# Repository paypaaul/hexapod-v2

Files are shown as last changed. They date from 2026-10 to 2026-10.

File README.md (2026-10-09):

# Hexapod v2

Robot esapode a 18 gradi di libertà (6 zampe × 3 servo MG996R), stampato in 3D e comandato da un ESP32-S3 con camera e una SSC-32. Progetto personale, in fase di progettazione CAD.

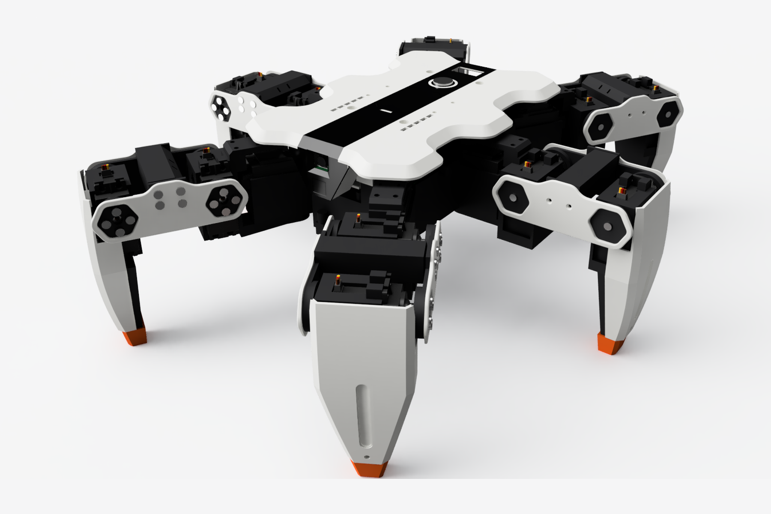
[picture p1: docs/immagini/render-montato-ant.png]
Render del robot (Fusion, colori per materiale)


Altri render: [da dietro](docs/immagini/render-montato-post.png), [di fianco](docs/immagini/render-montato-fianco.png), [esploso della zampa](docs/immagini/render-esploso-zampa.png), [esploso del corpo](docs/immagini/render-esploso-corpo.png).

## Dove guardare

| Documento | Contenuto |
|---|---|
| [Progetto meccanico](docs/progetto-meccanico.md) | zampa, corpo, assieme, verifiche di movimento, cavi, massa |
| [Decisioni](docs/decisioni.md) | registro delle scelte con il perché |
| [BOM](docs/BOM.md) | distinta base, schema di alimentazione, viteria, domande aperte |
| [Studio dei componenti](docs/studio-componenti.md) | servo, alimentazione, batteria, giunti, stampa |
| [Dimensionamento](docs/dimensionamento.md) | massa, geometria, coppie e assetti |
| [Dimensioni dei componenti](docs/dimensioni-componenti.md) | quote dei componenti con la fonte |
| [Ricerca](docs/ricerca/) | proposte e revisioni indipendenti di zampa e corpo |

## Cartelle

- `cad/script/`: script Python che costruiscono il modello in Fusion (`corpo.py`, `zampa.py`, `assieme.py`).
- `cad/stl/`: STL delle parti già pronte per i provini.
- `cad/modelli/`: fonti dei modelli STEP di terzi.
- `cad/render/`: render schematici del modello.
- `calc/`: calcoli di statica, andature, escursioni e cavi.

Lo stato del lavoro e i prossimi passi sono in [CLAUDE.md](CLAUDE.md).

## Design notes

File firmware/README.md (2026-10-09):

# Firmware dell'esapode

Firmware per l'ESP32-S3 (scheda UICPAL ESP32-S3-CAM N16R8) in **C++17 su ESP-IDF, senza Arduino**. Architettura in `docs/software.md` (capitoli 2 e 4); qui c'è la prima parte della fase S0: il nucleo provato sul PC e lo scheletro del firmware che compila.

## Struttura

```
firmware/
  CMakeLists.txt            progetto ESP-IDF (build minima: solo main e i componenti che richiede)
  sdkconfig.defaults        16 MB di flash, PSRAM octal, partizioni, OTA con ritorno, watchdog a 1 s
  partitions.csv            tabella di software.md 2.8, con due slot OTA da 4 MB
  main/                     app_main e compiti FreeRTOS (scheletri, vedi sotto)
  components/nucleo/        C++17 puro, senza dipendenze da ESP-IDF: si compila sul chip e sul PC
    include/nucleo/
      robot_generato.hpp    GENERATO da tools/genera_header.py (non si modifica a mano)
      tipi.hpp              vettori, angoli di una zampa, posa, maschera d'appoggio
      cinematica.hpp        diretta e inversa di zampa e corpo
      statica.hpp           carichi sui piedi, coppie stimate, margine di stabilità
      guardia.hpp           guardia del fotogramma intero (software.md 2.5)
      andatura.hpp          tripode a fase continua, identico a cad/script/assieme.py -> pose_tripode
      servo.hpp             angolo -> impulso, taratura, modello del servo per la posa prevista
  test_host/                test del nucleo sul PC: CMake, ctest, Unity, sanitizer
    vettori_generati.hpp    GENERATO da tools/genera_vettori.py
```

Fuori da `firmware/`: `tools/genera_header.py`, `tools/genera_vettori.py`, `tools/riferimento.py` (andatura di riferimento in Python), `tests/` (pytest), `ruff.toml`, `.github/workflows/ci.yml`.

## Versione di ESP-IDF

**ESP-IDF v6.1** (pubblicata il 27 agosto 2026): l'ultima versione stabile pubblicata da almeno due settimane al 9 ottobre 2026, ed è quella scelta in `docs/software.md` (tabella del capitolo 1). La stessa versione è fissata nel CI (`ESP_IDF_VERSIONE` in `.github/workflows/ci.yml`, immagine Docker `espressif/idf:v6.1`): si cambiano insieme.

Installazione sul Mac (fatta il 9 ottobre 2026, solo per l'esp32s3):

```sh
git clone -b v6.1 --depth 1 --recursive --shallow-submodules https://github.com/espressif/esp-idf.git ~/esp/esp-idf
~/esp/esp-idf/install.sh esp32s3
```

Gli strumenti stanno in `~/.espressif` (compilatore `xtensa-esp-elf` 15.2.0, ambiente Python `idf6.1_py3.12_env`). In `~/esp-idf` resta un'installazione precedente della v6.0: questo progetto usa `~/esp/esp-idf`.

## Compilare il firmware

```sh
. ~/esp/esp-idf/export.sh
cd firmware
idf.py build          # la prima volta crea sdkconfig da sdkconfig.defaults (sdkconfig non va in git)
idf.py size           # occupazione di flash e RAM
```

Risultato al 9 ottobre 2026: compila senza avvisi; `hexapod.bin` 174 KB, il 4 % dello slot OTA da 4 MB.

Non provato sul chip: la scheda non c'è ancora. Quando ci sarà: `idf.py -p <porta> flash monitor` (console sulla CH340).

## Provare il nucleo sul PC

```sh
cmake -S firmware/test_host -B firmware/test_host/build -G Ninja   # sanitizer attivi: -DNUCLEO_SANITIZER=OFF per toglierli
cmake --build firmware/test_host/build
ctest --test-dir firmware/test_host/build --output-on-failure -V    # -V stampa gli scarti misurati
```

Unity si scarica alla prima configurazione (FetchContent), alla stessa revisione che ESP-IDF v6.1 porta in `components/unity` (v2.6.0_RC1), con l'hash dell'archivio controllato. Nucleo e test si compilano con `-Wall -Wextra -Wpedantic -Wshadow -Wdouble-promotion -Werror` e, di default, con AddressSanitizer e UndefinedBehaviorSanitizer.

Cosa controllano (criteri di `docs/software.md` 6.3) e cosa si è misurato il 9 ottobre 2026 con Apple clang 21 (uguale in Debug con i sanitizer e in Release):

| Prova | Criterio | Misurato |
|---|---|---|
| Diretta contro il CAD (`robot/pose_cad.json`, 75 pose) | ≤ 0,05 mm | 0,00009 mm |
| Diretta contro `tools/descrizione.py` (810 punti) | ≤ 0,001 mm | 0,00005 mm |
| Inversa contro il Python, andata e ritorno | ≤ 0,01° | 0,0004° (punta ritrovata a 0,0004 mm) |
| Inversa delle punte lette dal CAD (66 pose) | ≤ 0,01° | 0,002° |
| Andatura contro i cicli del CAD (arrotondati a 0,01°) | ≤ 0,006° | 0,005° |
| Andatura contro `tools/riferimento.py` (240 pose a fasi diverse) | ≤ 0,01° | 0,00003° |
| Pose dei 6 cicli verificati nel CAD | nessun limite geometrico violato | nessuno; a 70/70 rifiuto per la coppia (sotto) |
| Casi d'urto: femore a −60°, vicine a 40° una verso l'altra, ginocchio sotto la tabella | rifiutati | rifiutati con il motivo giusto |
| Statica contro `calc/statica_tripode.py`, riga per riga | carichi ≤ 1e-4 kgf, coppie ≤ 1e-3 kgf·cm | 5e-7 kgf, 5e-6 kgf·cm |
| Regressione a 100/45 | femore al 51 % ± 1, margine 59 mm | 51,38 % (5,651 kgf·cm), 59,21 mm |
| Andatura a 50 Hz, ciclo da 1,2 s, tre cicli per assetto | nessun salto oltre 250°/s; piedi in appoggio fermi ≤ 0,5 mm | salto massimo 4,06° a fotogramma (203°/s); piedi fermi entro 0,0002 mm |
| Partenza, rotazione e arresto con la rampa dei parametri | ogni fotogramma accettato dalla guardia | 360 fotogrammi accettati, salto massimo 3,8° |

**Coppia a 70/70.** Le pose del ciclo a tripode a 70/70 (e della rotazione sul posto a 70/70) passano tutti i limiti geometrici, ma la coppia stimata arriva al 75 % (74 % nella rotazione) dello stallo, oltre il rifiuto al 70 % di `robot.yaml`; la tabella del 4.2 di `software.md` dà lo stesso 75 %. Nel CAD si è verificata l'assenza di urti, non la coppia. La guardia li rifiuta: a 70/70 il firmware dovrà usare un'andatura con più piedi a terra. Il test lo controlla esplicitamente.

## Test Python e file generati

```sh
python3 -m venv .venv && .venv/bin/pip install -r tests/requirements.txt
.venv/bin/python -m pytest tests            # descrizione contro il CAD, statica, file generati aggiornati
.venv/bin/ruff check .
```

`robot_generato.hpp` e `vettori_generati.hpp` si rigenerano dopo ogni modifica di `robot/robot.yaml` o una nuova esportazione dal CAD (prima `python3 tools/descrizione.py --aggiorna-hash`):

```sh
python3 tools/genera_header.py
python3 tools/genera_vettori.py
```

L'uscita è deterministica; il CI la rigenera e fallisce se differisce da quella nel commit, o se `cad_sha256` di `robot.yaml` non è quello di `cad.json`.

## La guardia

Un fotogramma (posa delle 18 articolazioni più i piedi a terra) è accettato solo se rispetta tutti i limiti di `robot.yaml -> guardia`: imbardata ±30°, somma tra vicine entro 56° con i segni di `robot.yaml` (a sinistra imb_A − imb_M e imb_M − imb_P, a destra il contrario), femore da −45° a +82°, ginocchio da γmin(α) + 3° (fra due righe della tabella vale il massimo) a 177°, corsa ±80° attorno al calettamento, 250°/s per giunto rispetto al fotogramma precedente, baricentro ad almeno 20 mm dai lati del poligono d'appoggio, coppia stimata sotto il 70 % dello stallo (oltre il 55 % e il 60 % dà il livello di avviso e di tempo limitato, che userà la macchina a stati). Il singolo giunto non si tronca mai: l'esito dice il primo motivo del rifiuto (zampa, giunto, valore, limite) e tutti i limiti violati; chi comanda tiene il fotogramma precedente o riduce il comando. I limiti morbidi possono solo stringere quelli rigidi (`LimitiGuardia::stringi`).

Ipotesi della statica, le stesse di `calc/`: corpo orizzontale, baricentro al centro del corpo, forze ai piedi verticali. Con più di tre piedi a terra il problema è iperstatico e il nucleo prende la ripartizione a norma minima (S): la ripartizione vera dipende dalle cedevolezze.

## Cosa è uno scheletro

I compiti di `docs/software.md` 2.2 esistono tutti, con il loro core, la priorità e il ritmo; nel codice sono marcati `SCHELETRO`.

| Compito | Core | Priorità | Ritmo | Oggi |
|---|---|---|---|---|
| `ctrl` | 1 | 22 | 50 Hz da un timer hardware, interruzione sul core 1 | **fa il ciclo del nucleo in modo OMBRA**: andatura a tripode a 100/45, IK del corpo, guardia, impulsi, posa prevista; niente alla SSC-32, rail spento. Si iscrive al watchdog. Ogni secondo scrive nel log cicli, rifiutati e durata massima del ciclo |
| `sens` | 1 | 20 | 100 Hz | gira a vuoto |
| `infer` | 1 | 3 | 5 Hz | gira a vuoto |
| `comm` | 0 | 15 | a evento | gira a vuoto |
| `cam` | 0 | 10 | 15 Hz | gira a vuoto |
| `telem` | 0 | 8 | 50 Hz | gira a vuoto |
| `servizio` | 0 | 3 | a evento | gira a vuoto |

All'avvio `app_main` porta GPIO42 (rail dei servo) basso, scrive versione e impronta di `cad.json`, fa un autotest del nucleo (la posa iniziale dell'andatura deve passare la guardia) e solo allora avvia i compiti.

Mancano: macchina a stati e sequenza d'accensione (2.6), driver della SSC-32 (2.4), comandi e rete, sensori, telemetria, taratura in NVS (2.7), OTA con autotest (2.8), andature a coppie e a onda, politica.

## Partizioni

| Partizione | Indirizzo | Dimensione |
|---|---|---|
| `nvs` | 0x9000 | 24 KB |
| `nvs_cal` (taratura) | 0xF000 | 16 KB |
| `otadata` | 0x13000 | 8 KB |
| `phy_init` | 0x15000 | 4 KB |
| `ota_0` | 0x20000 | 4 MB |
| `ota_1` | 0x420000 | 4 MB |
| `coredump` | 0x820000 | 64 KB |
| `storage` (LittleFS) | 0x830000 | 7,8 MB, fino a 16 MB |

Gli indirizzi non vanno cambiati dopo la prima installazione: l'OTA non riscrive la tabella.

## Integrazione continua

`.github/workflows/ci.yml`, quattro job: `python` (ruff e pytest), `nucleo` (CMake e ctest con i sanitizer, con gcc e con clang), `firmware` (ESP-IDF v6.1 installato dal repository di Espressif come sul Mac, con la cache: senza Docker, perché il 9 ottobre Docker Hub non rispondeva ai runner; dimensione dell'immagine contro lo slot OTA, binari allegati), `generati` (impronta di `cad.json`, header e vettori rigenerati, `git diff --exit-code`).

**Passo successivo: il job `qemu`** (`software.md` 6.4). Una configurazione dedicata del firmware (per esempio `sdkconfig.qemu` con la console sulla UART0 e senza camera, Wi-Fi e sensori) si avvia nel QEMU di Espressif per l'esp32s3 (`idf.py qemu`, nell'immagine Docker dell'IDF), stampa versione e autotest e, in uno scenario scritto, emette i comandi attesi per la SSC-32; il job confronta l'uscita. Prova la macchina a stati e il nucleo, non lo stack completo: il QEMU dell'S3 non emula Wi-Fi, Bluetooth, USB, I2C, RMT né la matrice dei GPIO. Serve prima il driver della SSC-32 con il backend simulato, e va verificato se la UART1 è emulata; se non lo è, lo scenario usa la console.

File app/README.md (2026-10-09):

# Gemello digitale nel browser (app/)

Il robot in 3D, dall'URDF generato (`robot/generati/esapode.urdf`) con le mesh dei segmenti esportate dal CAD, che
riproduce il **tripode** e la **rotazione sul posto**. Cursori per h (altezza dell'asse dei femori), xf0 (distanza del
piede dall'asse del femore), giro (gradi di rotazione del corpo a ogni passo) e periodo del ciclo. È la prima forma del
gemello di `docs/software.md` 6.6; poi l'app servita dal robot mostrerà le pose comandate e previste che arrivano dalla
telemetria.

**Le pose sono comandate, non misurate**: le calcola il generatore d'andatura e l'app lo scrive in cima al pannello. Il
corpo si sposta come farebbe se i piedi in appoggio non scivolassero. La guardia (ginocchio minimo, somma tra vicine,
velocità) qui non c'è: l'app segnala in rosso solo gli angoli oltre i fine corsa meccanici dell'URDF.

## Come si usa

Serve Node.js 22.18 o più recente (`brew install node`). Nessun servizio esterno: tutto è nella build.

```
cd app
npm ci
npm run dev          # http://localhost:5173, ricarica a ogni modifica
npm test             # formule contro il CAD (node:test, senza compilazione)
npm run build        # dist/, da servire come file statici (anche dal robot)
npm run dimensione   # controlla la dimensione di dist/
```

Una vista si può condividere con l'indirizzo: `?andatura=rotazione&h=70&xf0=70&giro=20&periodo=1.5&fase=0.3`.

## Cosa c'è

| Percorso | Contenuto |
|---|---|
| `src/andatura.ts` | tripode e rotazione sul posto, con la cinematica inversa: stesse formule di `cad/script/assieme.py` → `pose_tripode` e di `sim/andatura.py` |
| `src/geometria.ts` | coxe, Lc, Lf, Lt e limiti letti dall'URDF |
| `src/main.ts` | scena three.js, caricamento con urdf-loader, comandi, animazione |
| `scripts/modelli.mjs` | prepara `public/modelli/` (generata, ignorata da git): copia l'URDF e converte gli STL in GLB compatti |
| `scripts/dimensione.mjs` | limiti della build: modelli sotto 1 MB, totale sotto 2 MB |
| `test/andatura.test.ts` | geometria uguale a `cad.json`, pose uguali a `cad.json` → `cicli_verificati` entro 0,01°, costanti uguali a `robot.yaml` |

### Perché le pose le calcola il TypeScript

I cursori sono continui: con le pose precalcolate in Python servirebbe una griglia di h × xf0 × giro × fasi, pesante
e comunque a scatti. Le formule sono poche righe e restano uguali alle altre grazie al test, che le confronta con le
stesse pose del CAD usate per il generatore Python e per il nucleo C++. Le costanti che l'URDF non contiene (tripodi,
assetto, passo, alzata) sono in `src/andatura.ts` e il test le confronta con `robot.yaml`.

### Mesh

Gli STL dei segmenti pesano 2,4 MB (il corpo 2 MB). `scripts/modelli.mjs` salda i vertici ripetuti, scrive le
posizioni come interi a 16 bit con passo di 0,01 mm (estensione glTF KHR_mesh_quantization) e lascia fuori le normali
(ombreggiatura piatta): 444 KB in tutto, senza decimare e senza dipendenze. Build intera: circa 1,2 MB (three.js è
quasi tutto il resto).

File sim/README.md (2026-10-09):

# Simulazione (sim/)

Gemello fisico del robot in MuJoCo, comandato come il robot vero: comandi ASCII della SSC-32, impulsi ogni 20 ms,
servo senza retroazione. È la parte "SIL" della fase S0 (`docs/software.md`, 6.5 e 7).

## Cosa c'è

| File | Contenuto |
|---|---|
| `modello/esapode.xml` | MJCF **generato** da `tools/genera_modelli.py`: non si modifica a mano |
| `ssc32_emu.py` | emulatore della SSC-32 (`SSC32`) e conversione impulsi ↔ angoli con `robot.yaml` (`Canali`) |
| `servo.py` | modello dei servo attorno agli attuatori dell'MJCF: banda morta, servo liberi, coppia all'uscita |
| `andatura.py` | tripode e rotazione sul posto in Python: porting di `cad/script/assieme.py` → `pose_tripode` |
| `simulazione.py` | catena completa: comandi → emulatore → servo → fisica a passi di 2 ms |
| `sil.py` | prova SIL del tripode a comandi aperti, con le misure; si lancia anche da riga di comando |
| `tests/` | test con pytest, senza schermo |
| `requirements.txt` | versioni fissate (MuJoCo 3.14.0) |

## Come si usa

Dalla radice della repo, con un ambiente virtuale (`.venv`, ignorato da git):

```
python3 -m venv .venv && printf '*\n' > .venv/.gitignore
.venv/bin/pip install -r sim/requirements.txt
.venv/bin/python tools/genera_modelli.py            # rigenera URDF e MJCF dopo un cambio di robot.yaml o cad.json
.venv/bin/python tools/genera_modelli.py --controlla
.venv/bin/python -m pytest sim/tests -q              # circa 3 s
.venv/bin/python sim/sil.py                          # 20 s di tripode a 100/45, stampa le misure
.venv/bin/python sim/sil.py --giro 30                # rotazione sul posto
.venv/bin/python sim/sil.py --h 70 --xf0 70          # altri assetti
.venv/bin/python -m mujoco.viewer --mjcf sim/modello/esapode.xml   # per guardarlo (con lo schermo)
```

Nel visualizzatore i gruppi 2 e 3 sono le mesh e le primitive di collisione; la posa "in_piedi" è fra i keyframe.

## Il modello

- Un corpo libero e tre segmenti per zampa, con lo zero dei giunti nella posa "come costruita" del CAD:
  `g_coxa_<z>` = imbardata, `g_femore_<z>` = alpha (asse −Y), `g_ginocchio_<z>` = gamma − 90 (asse −Y). Fine corsa
  meccanici da `cad.json`; la tabella del ginocchio minimo non c'è, la applica la guardia.
- Masse e inerzie: somma delle parti di `cad.json` per segmento, con il trasporto al baricentro; i 360 g non modellati
  sul corpo, distribuiti come il corpo. Massa totale 2943,2 g (`robot.yaml` dice 2945).
- Collisioni con primitive ricavate da `cad.json` e dalle mesh: chiglia, scafo, carapace e sei lobi per il corpo; la
  culla del servo del femore per la coxa; due capsule (una per fianco) per il femore; culla, stinco e sfera del piede
  (raggio 5,6 mm) per la tibia. Riproducono il CAD: due vicine si toccano fra 31 e 32 gradi ciascuna, il ginocchio
  minimo sta da 1 grado sotto a 4 sopra la tabella del CAD, nessun urto nelle 64 pose verificate.
- Sensori: contatto (`touch`) per ogni piede, IMU (accelerometro, giroscopio, assetto) al centro del vano sotto il
  vassoio (`predisposizioni.md`, X4; la x esatta è da fissare, C).
- Contatti: attrito 0,8 (centro della randomizzazione di `software.md` 4.4, S) e `solref` 0,005 s. Con il valore di
  MuJoCo (0,02 s) il contatto è cedevole e cambia i risultati: vedi sotto.

### Servo

| Grandezza | Valore | Da dove |
|---|---|---|
| Coppia massima (`forcerange`) | 1,079 N·m | stallo 11 kgf·cm a 6 V (V) |
| Smorzamento del giunto | 0,144 N·m·s/rad | stallo / velocità a vuoto (0,14 s/60° = 7,48 rad/s, V): la retta coppia-velocità del motore a piena tensione |
| `kp` | 12,4 N·m/rad | stallo raggiunto a 5° di errore (S, da identificare: `software.md` 4.6) |
| Banda morta | ±2,5 µs = ±0,225° | larga 5 µs (V), in gradi con 11,1 µs/° (S); applicata da `servo.py` |

Mancano ritardo proprio del servo, gioco, offset di taratura e variazione con la tensione: arrivano con
l'identificazione dei servo (S4). Il ritardo degli impulsi (un fotogramma da 20 ms) c'è già, dall'emulatore.

## Emulatore della SSC-32

Comandi ASCII: gruppi `#<ch>P<us>[S<us/s>]…[T<ms>]`, `#<ch>P0`, `STOP <ch>` e `#<ch>STOP`, `Q`, `QP <ch>`, `VER`;
`<esc>` annulla la riga. Interpolazione lineare dei gruppi, un fotogramma di impulsi ogni 20 ms, campo 500–2500 µs.
Uscita verso i servo con canali, versi, calettamento e µs per grado di `robot.yaml`.

Da confrontare con il clone al banco (S1, passo B1): comportamento dopo `P0`, troncamento di `QP`, stringa di `VER`,
tempi di risposta. Il modo binario e il tempo di trasmissione sulla seriale non ci sono ancora.

## Prova SIL (tests/test_sil.py)

Un "firmware" Python manda ogni 20 ms un gruppo con i 18 canali e `T20`; nessuna retroazione. Assetto 100/45, passo
60, alzata 30, periodo 1,0 s (120 mm/s; velocità comandate fino a 215°/s, sotto i 250 della guardia), rampa di passo
e giro sul primo ciclo, poi 20 s. Si prova il tripode dritto e la rotazione sul posto di 30° a passo.

| Verifica | Soglia e perché | Dritto | Giro 30 |
|---|---|---|---|
| Non cade | asse dei femori sopra h − alzata/2 = 85 mm; inclinazione sotto la posa sicura a 100/45 (25°, `software.md` 2.6); solo i piedi a terra | 97,8–99,2 mm; 0,20° | 97,7–99,2 mm; 0,14° |
| Urti fra parti | nessuno | nessuno | nessuno |
| Scivolamento dopo l'atterraggio | spostamento del piede lasciato libero dalla banda morta dei tre servo: 1,26 mm | 0,53 mm | 0,54 mm |
| Scivolamento per appoggio intero | 10 % del passo, 6 mm | 2,73 mm | 4,03 mm |
| Avanzamento o rotazione | entro il 10 % del comandato | 2305 mm su 2340 | 1143° su 1170 |
| Coppia | sotto il 60 % dello stallo (`robot.yaml` → guardia) | coxa 43 %, femore 51 %, ginocchio 49 % | 52 %, 52 %, 35 % |

Numeri del 9 ottobre 2026, macOS. Il femore al 51 % coincide con `calc/statica_tripode.py` (51,4 %).

Cose da sapere:

- **Atterraggio**: il volo di `pose_tripode` torna avanti a velocità costante e il piede arriva a terra ancora in moto
  (240 mm/s rispetto al pavimento): striscia 2–3 mm nei primi 50 ms dell'appoggio, poi resta fermo. Il generatore del
  firmware, con una Bézier che arriva a velocità zero (`software.md` 4.2), dovrebbe toglierlo.
- **Partenza**: senza la rampa (`sil.py --avvio 0`) il tripode d'appoggio passa da fermo a 120 mm/s in un fotogramma e
  il ginocchio posteriore tocca il 76 % dello stallo per qualche decina di millisecondi; a regime resta sotto il 50 %.
- **Rigidezza dei contatti**: con il `solref` di MuJoCo (0,02 s) il corpo cede di più, i piedi caricati strisciano fino
  a 3 mm e il femore tocca l'83 % agli atterraggi: la prova non passerebbe. Con 0,01 s: 1,5 mm e 58 %. Il valore
  scelto (0,005 s) è il più rigido stabile con il passo di 2 ms; va confermato confrontando simulazione e robot (S4).
- Altri assetti, senza asserzioni (stessa prova, `sil.py --h … --xf0 …`): nessuno cade né urta, ma negli assetti bassi
  la coppia sale e i piedi caricati strisciano oltre la soglia di 100/45 (in tutti la soglia vale 1,26 mm calcolata
  a 100/45):

  | Assetto | Coppia massima coxa / femore / ginocchio | Scivolamento dopo l'atterraggio, massimo |
  |---|---|---|
  | 130/25 | 41 / 51 / 50 % | 1,63 mm |
  | 80/60 | 41 / 59 / 56 % | 1,36 mm |
  | 70/70 | 35 / 81 / 66 % | 2,18 mm |

  A 70/70 il tripode supera il 60 % (in `docs/software.md` 4.2 il calcolo statico dà 75 %): conferma che negli assetti
  bassi serve l'andatura a coppie o a onda.

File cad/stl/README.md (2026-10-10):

# STL delle parti stampate

Esportati da Fusion il 10 ottobre 2026 (design "Hexapod v2.1.0", dopo D-066) con `cad/script/esporta_stl.py`. Ogni file è nella terna del suo componente: terna della zampa per le parti della zampa, terna del robot per quelle del corpo. Gli orientamenti qui sotto sono proposte: li confermi tu nello slicer. Sono file di prova: le quote marcate C (squadretta, giochi, forzamenti) si confermano con il provino.

Materiali (scelta dell'utente, D-065): **PETG-CF nero** per le parti funzionali, **PLA** per le placche (bianco per ora; fascia, visiera, gonne e sportellino in un secondo colore, nero), **TPU 95A arancio** per i piedini.

## Zampa (sei di ognuna)

| File | Materiale | Orientamento di stampa proposto | Note |
|---|---|---|---|
| `Tibia.stl` | PETG-CF | fondo della culla (faccia −Y) sul piatto, apertura della culla in alto | **provino della culla**: contiene una culla completa. Lo stinco è simmetrico sul piano della zampa (D-065) e si stacca dal piatto verso la punta (fino a circa 17 mm): serve un supporto a cuneo sotto lo stinco. Dalla 2.1.1 c'è la gola dei fili sulla parete +X della culla con tre ponticelli: in questa posizione crescono come pareti in piedi, senza supporti (D-067) |
| `Coxa.stl` | PETG-CF | faccia +Y (orlo della culla, braccio, anima) sul piatto | foro del perno orizzontale in stampa |
| `Coxa_Ponte.stl` | PETG-CF | faccia superiore sul piatto (sede del disco verso l'alto) | |
| `Femore_B.stl` | PETG-CF | faccia esterna della piastra dei perni sul piatto | blocco in piedi; due fori per inserti M2 sulla faccia esterna (lama B) |
| `Femore_A.stl` | PETG-CF | faccia esterna sul piatto | sedi delle squadrette verso l'alto |
| `Cover_Femore_A.stl` | PLA | faccia interna (piana) sul piatto, bombatura in alto | si incastra sulle teste M3 del blocco |
| `Cover_Femore_B.stl` | PLA | faccia interna (piana) sul piatto, bombatura in alto | due fori svasati per viti M2 × 6 a testa piana (D-065) |
| `Cover_Tibia.stl` | PLA | retro aperto sul piatto, fronte in alto | il fronte fa da ponte fra i due smussi; supporti piccoli sotto i due tappi e il bossolo della vite |
| `Piedino.stl` | TPU 95A | bocca sul piatto, punta in alto | calza la punta dello stinco; nel modello la stretta è zero, da tarare sul provino (0 / −0,2 / −0,4 mm). Dalla 2.1.0 la suola è piana, con il pistoncino per l'FSR dentro e la tacca dei fili (D-066) |
| `Cover_Tibia_Diffusore.stl` | PLA bianco (o PETG traslucido fumé) | lastra sul piatto, bordino in alto | solo con le luci nelle tibie: si incastra da dentro nella finestra del guscio (D-066) |

## Corpo

| File | Materiale | Orientamento di stampa proposto | Note |
|---|---|---|---|
| `Corpo_Carapace.stl` + `Corpo_Fascia.stl` + `Corpo_Visiera.stl` + `Corpo_Gonne.stl` | PLA bianco (carapace) e PLA nero (gli altri tre) | capovolto, faccia a z 36 sul piatto | **un solo pezzo a due colori**: caricare i quattro file insieme (sono già allineati) e assegnare il materiale per oggetto; senza supporti |
| `Corpo_Sportello_Servizio.stl` | PLA nero | faccia in vista sul piatto | |
| `Corpo_Sportello.stl` | PETG-CF | faccia esterna (smussata) sul piatto | |
| `Corpo_Base.stl` | PETG-CF | vedi le note di stampa in D-056 | |
| `Corpo_Chiglia.stl` | PETG-CF | fondo sul piatto | |
| `Corpo_Vassoio.stl` | PLA (sta sotto l'antenna: niente carbonio) | piano sul piatto | |
| `Corpo_Slitta_Regolatore.stl` | PETG-CF | due copie | |
| `Corpo_Supporto_INA260_S.stl`, `Corpo_Supporto_INA260_D.stl` | PETG-CF | piastra sul piatto | solo con gli INA260 (X7): si appoggiano alla slitta e prendono la sua vite (M3 più lunga di 2,4) |
| `Corpo_Tappo_ToF.stl` | PLA nero | flangia sul piatto | chiude la finestra del ToF frontale finché il sensore manca |
| `Corpo_Fondo_Anello.stl` | PLA nero | disco sul piatto, gonna e sedi dei pixel in alto | chiude da sotto la camera nera dell'anello del pulsante: si infila sul corpo del pulsante dopo il dado e calza la parete della camera (forzamento leggero, D-067). Nelle due sedi va un pixel di striscia ciascuna, LED in su |
| `Corpo_Sportello_Servizio_Zaino.stl` | PLA nero | come lo sportellino | al posto dello sportellino, solo con il computer a zaino (tacca per l'USB-C) |

Parti in PETG-CF: ugello temprato 0,4, pareti 3 perimetri (1,2 mm), 4–5 strati sopra e sotto, riempimento 25 %.

## Attrezzi da banco (`attrezzi/`, D-066)

| File | Materiale | Orientamento di stampa proposto | Note |
|---|---|---|---|
| `attrezzi/Dima_Posa_1.stl`, `attrezzi/Dima_Posa_2.stl` | PLA o PETG | piastra sul piatto, denti in alto | dime di taratura: si infilano sui perni del femore dal lato B (lama B tolta); posa 1: imbardata 0, femore 0, ginocchio 90; posa 2: 30, 45, 135 |
| `attrezzi/Attrezzo_Cavalletto.stl` | PETG-CF | base sul piatto | regge il robot sotto la chiglia con le zampe libere; alto 137 mm |
| `attrezzi/Attrezzo_Provino_Luce_Nero.stl` + `attrezzi/Attrezzo_Provino_Luce_Bianco.stl` | PLA nero + PLA bianco, in una stampa a due colori | fondo sul piatto, bianco in alto (le strisce di bianco fanno ponte sulle camere) | provino di luce (X10, D-069): camere da 2, 4 e 6 mm sotto bianchi da 0,4 a 1,6 e l'anello del pulsante con l'intarsio nero; uno spezzone di striscia da 120 LED/m nei canali sotto |

## Provino della culla (da stampare per primo)

Stampare `Tibia.stl` e provare con un MG996R vero, senza gommini:

1. il servo deve scendere nella culla con il passacavo nella fessura dall'orlo alla finestra (D-049); la spina JR passa prima dalla finestra;
2. le due viti M3 × 8 lato coda negli inserti, le due lato albero nei fori pilota Ø2,5: il servo deve restare fermo senza gioco;
3. il cuscinetto LF-1050ZZ nella sede del fondo (Ø10 nominale): forzamento da regolare con il parametro `cus_sede_d`;
4. giochi della sede del servo (`gio_servo`, 0,2 per lato) e nervature di schiacciamento da decidere sul provino.

Il provino del giunto completo (ponte, squadretta, perni) aspetta la squadretta metallica comprata: le sue quote (`sq_*`) sono ancora stimate. Provini della passata estetica: tubo Ø5,4/5,6/5,7 su una testa M3 (lama A), tappo a rombo, nervature dello sportellino, collare del cicalino, stretta del piedino, inserti del kit Temu nei fori `ins_m3_d` e `ins_m2_d`.

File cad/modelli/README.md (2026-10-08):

# Modelli 3D di terzi

I file `.step` stanno qui ma non in git (`.gitignore`): si riscaricano dalle fonti.

| Cartella | File | Fonte | Note |
|---|---|---|---|
| `mg996r/` | `Servo Motor MG996R 3D Model.step`, `Servo MG996R Horn.step` | modello di Dejan Nedelkovski (HowToMechatronics, 2020), copia nel repository GitHub [Matthew-Garcia/SCARA-Robot](https://github.com/Matthew-Garcia/SCARA-Robot/tree/main/3D_Models), scaricata l'8 ottobre 2026 | unità mm, Y verso l'alto; confronto con il datasheet in `docs/dimensioni-componenti.md` |
| `pololu-d42v110fx/` | `d42v110fx.step` | [pololu.com/file/0J2219](https://www.pololu.com/file/0J2219/d42v110fx-step-down-voltage-regulator.step) | regolatore dei servo; stesso ingombro del D24V150Fx |
| `pololu-d24v22fx/` | `d24v22fx.step` | [pololu.com/file/0J1413](https://www.pololu.com/file/0J1413/d24v22fx-step-down-voltage-regulator.step) | regolatore da 5 V della logica |

Per riscaricare il modello del servo con `gh`:

```bash
gh api -H "Accept: application/vnd.github.raw" "repos/Matthew-Garcia/SCARA-Robot/contents/3D_Models/Servo%20Motor%20MG996R%203D%20Model.step" > "cad/modelli/mg996r/Servo Motor MG996R 3D Model.step"
```

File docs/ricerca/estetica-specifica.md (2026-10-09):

# Passata estetica: specifica della versione scelta (Kabuto corretto)

Generata il 9 ottobre 2026 dalla sintesi del confronto tra tre concept (giuria di tre giudici). Concept, render e giudizi completi in `estetica.json` e nella cartella `estetica/`. **Da approvare dall'utente prima di modellare.**

## Perché

Tutti e tre i giudici (estetica, funzione, CAD) mettono Kabuto primo, con voto 7. È l'identità più forte e leggibile: un guscio bianco sfaccettato con i lobi perpendicolari alle zampe, la fascia nera sull'asse, la regola "chiaro = armatura, scuro = struttura". È anche il più leggero (+70 g nel concept, +74 g in questa sintesi), quello con meno pezzi (3 per zampa) e il più costruibile con le primitive già provate. I suoi problemi bloccanti sono tutti correggibili.
- Sedi della lama A fuse e teste e rondelle sovrapposte: è un difetto del femore di oggi; si spostano gli inserti del blocco.
- Testa "a scatola": diventa una visiera nera rastremata a 60°.
- Schiniere troppo grande: diventa una ginocchiera a scudo solo sulla culla.
- Fascetta nera sul bianco: va dentro il blocco del femore. Questo risolve anche l'urto, già presente oggi, contro la testa dell'anima da α 74°.
- Retro disordinato: guance e sportello bianco fanno da cornice alla porta.
- Altri: piega dello schiniere che compenetra la tibia (tolta), spina e foro con lo stesso parametro (separati), coda degenere (ora 1 mm oltre il vertice del lobo), massa (ricontrollata con la statica: femore al 49 %).

Gli altri due concept non reggono come base:
- Ciottolo dipende da raccordi API mai provati e pesa +171 g. Ha errori di quota bloccanti: pinne, cicalino nel raccordo, asola e cuffie prigioniere.
- Lamina ha il miglior muso e la miglior coda, ma da lontano resta un robot nero con lamine sparse.

Delle idee di Ciottolo e Lamina ho preso solo quelle che restano nel linguaggio a 60°/45° di Kabuto.

## Innesti dagli altri concept

- Da Ciottolo: lame del femore lunghe da mozzo a mozzo con finestre sui mozzi. Qui le finestre sono esagonali (apotema 11), con le viti delle squadrette a vista e raggiungibili.
- Da Ciottolo: faccia esterna della lama A a filo delle teste M3 (Y 33,55), così la zampa non si allarga. Le zampe vicine toccano a 31,5° invece di 31,7°.
- Da Ciottolo: piedini in TPU arancio come unico accento di colore, senza pezzi in più (voce D9/E3).
- Da Ciottolo: facce in vista stampate sul PEI testurizzato (carapace capovolto, cover a faccia in giù), per avere la stessa grana ovunque.
- Da Ciottolo: teste delle viti M3 modellate come ingombro (Ingombro_Teste_A) prima delle verifiche tra zampe vicine; ingombro del pulsante Rif_Pulsante_12; documento di prova per le funzioni API nuove.
- Da Lamina: valli del carapace a y 56, che nascondono dall'alto le bugne delle slitte dei regolatori (y 50…55,7).
- Da Lamina: coda come pannello di servizio. Due guance bianche ai lati della porta, tettoia del carapace sopra e sportello della batteria bianco sotto chiudono di lato il vano del T-plug e del cicalino.
- Da Lamina: fronte del corpo chiuso dietro la testa da due paratie (|y| 15…28,5), così ai lati del muso non si vede più l'elettronica.
- Da Lamina: casi di controllo dichiarati per ogni verifica e misura della distanza minima con measureMinimumDistance.
- Dai giudici: la fascia nera scende dalla schiena sul viso e diventa una visiera nera che contiene l'occhio; i fianchi della testa sono a 60° fino al mento; ins_blocco_gb spostato; parametri distinti per spina e foro; cicalino aggiunto in pose_corpo; VOLUMI_ATTESI creato (oggi non esiste).

## Come sarà

Il robot avrà un guscio bianco opaco, basso e sfaccettato, con sei lobi esagonali proprio sopra le zampe e uno smusso a 45° tutto intorno. Al centro corre una fascia nera dalla coda alla testa. Contiene lo sportellino dell'USB-C, il pulsante d'accensione e la finestra del display del cicalino. Davanti la fascia scende sul viso e diventa una visiera nera a forma di scudo, larga in alto e stretta al mento, con l'occhio della camera. La incorniciano le due punte bianche del guscio. Sotto il guscio tutto è scuro: scafo, servo, gonne laterali nere. Su ogni lato del femore c'è una lama bianca lunga quanto l'osso, con le punte a esagono e due finestre esagonali sui giunti, da cui si vedono viti e perni. Sul ginocchio c'è uno scudo bianco a punta; lo stinco resta nero e finisce con un piedino arancio, l'unico colore. Dietro, tra due montanti bianchi, si apre la porta di servizio con T-plug, fusibile e spinotto del cicalino, sopra lo sportello bianco della batteria. Il robot pesa circa 75 g in più (circa 2,8 kg) e le zampe si muovono come oggi.

## Specifica

# Specifica: "Kabuto corretto", sintesi della passata estetica (proposta D-060)

Quote in mm. Terna del robot: X avanti, Y a sinistra, Z in alto, z 0 sugli assi dei femori. Terna della zampa: X verso l'esterno, Y verso Femore_A, Z in alto. Posa di riferimento: α 0, γ 90.

Riferimenti:
- conti: `/Users/paul/.claude/jobs/3d86073b/tmp/estetica/sintesi/calc/verifiche.py`, da copiare in `calc/` con D-060;
- render: `/Users/paul/.claude/jobs/3d86073b/tmp/estetica/sintesi/concept.py`.

Le chiamate scritte `p.blocco(...)`, `p.blocco_obl(...)`, `p.cilindro(...)` e `p.specchia(...)` sono quelle di `lib_cad.Parte`, con la firma di oggi.

## 0. Regole comuni

**Colore e funzione.** Una sola regola di colore:
- **bianco** (PETG bianco opaco) = armatura che non porta niente: carapace, guance, lame dei femori, ginocchiere, sportello della batteria;
- **nero** (PETG nero NON caricato) = interfacce: fascia, visiera con l'occhio, gonne, sportellino di servizio;
- **antracite** (PETG-CF) = struttura, invariata: giunti, culle, servo e viti a vista;
- **arancio** (TPU 95A) = solo i piedini.

Sopra l'antenna (x 55,6…81,1) solo PETG non caricato.

**Forma.**
- Due angoli soli: 60° in pianta e nelle sagome (lobi, punte delle lame, finestre dei mozzi, fianchi della testa, punta della ginocchiera) e 45° in sezione (smusso unico del carapace da 6 mm). Nessun raccordo.
- Spessori: pareti del carapace 1,6; cover 1,2; intarsio della fascia 0,6.

**Metodo.**
- Un componente per pezzo. I tagli toccano solo i corpi del componente (`lib_cad`).
- Dopo ogni blocco, in una chiamata a parte: stato, sentinella dei volumi, timeline senza avvisi, nessuna posa pendente.
- Nessuna chiamata oltre i 40 s.

**Acquisti.** Nessuna voce nuova di minuteria. Da approvare solo i colori dei filamenti: E2 in PETG bianco, un PETG nero non caricato, E3 TPU arancio.

## 1. Parametri

### 1.1 Corpo (nuovi, `corpo.py` → PARAMETRI)

| Nome | Espressione | Valore | Commento |
|---|---|---|---|
| car_top | `cor_cop_z + 7.6 mm` | 36 | cima del carapace (6 mm d'aria in più sopra regolatori, cicalino e flat) |
| car_sp | `cor_cop_sp` | 1,6 | pareti del carapace |
| car_smusso | `6 mm` | 6 | smusso unico a 45° del contorno superiore, viso e coda compresi |
| car_lobo_R | `32.3 mm` | 32,3 | lobi esagonali sugli assi delle coxe, raggio ai vertici (vertici a 0°, 60°…) |
| car_lobo_a | `car_lobo_R * cos(30 deg)` | 27,97 | apotema |
| car_valle_y | `56 mm` | 56 | fondo delle valli tra i lobi: copre le bugne delle slitte (y 50…55,7) |
| car_viso_x | `102 mm` | 102 | viso, che sta tra le punte dei lobi anteriori (vertici a x 112,3) |
| car_coda_x | `cor_ang_x + car_lobo_R / 2 + 1 mm` | 97,15 | coda, 1 mm oltre il vertice del lobo posteriore (−96,15): topologia non degenere |
| car_testa_y | `30 mm` | 30 | semilarghezza dei rettangoli di testa e coda nel pieno; gli spigoli stanno 1,9 mm (testa) e 6,1 mm (coda) dentro i lobi |
| car_mento_z | `cor_muso_giu` | −1 | fondo della testa, sotto il vassoio (z 1) |
| car_mento_semi | `9.2 mm` | 9,2 | semilarghezza del mento. A 60° la parete interna resta a \|y\| 7,35, cioè 1,35 mm fuori da mensola e torretta (\|y\| 6) quando il carapace si sfila |
| car_testa_semi | `25.2 mm` | 25,2 | fianchi verticali della testa, 0,96 mm dentro lo spigolo del viso (y 26,16) |
| car_testa_x0 | `cor_vas_x1 + 0.6 mm` | 82,6 | retro della parte bassa della testa (il vassoio arriva a x 82) |
| car_rastr | `60 deg` | 60 | fianchi della testa; la rastremazione arriva a car_testa_semi a z 26,71 |
| car_paratia_y0 | `15 mm` | 15 | paratie dietro la testa, da qui (ESP32 fino a \|y\| 14,15; punta dell'antenna a x 81,1) |
| car_paratia_y1 | `28.5 mm` | 28,5 | fino a qui (fronte del corpo \|y\| ≤ 27; gondola anteriore da \|y\| 30,2 a x 81) |
| car_fascia_semi | `17 mm` | 17 | fascia nera |
| car_fascia_h | `0.6 mm` | 0,6 | intarsio (3 strati da 0,2) |
| car_pozzo_d | `7 mm` | 7 | pozzetti delle viti |
| car_pozzo_D | `9.4 mm` | 9,4 | tubo dei pozzetti |
| car_serv_semi | `16 mm` | 16 | apertura di servizio \|y\| ≤ 16 (prima 17: la fascia resta larga 1 mm ai lati); x da cor_serv_x0 a cor_serv_x1 |
| car_serv_smusso | `6 mm` | 6 | angoli a 45° dell'apertura (ottagono) |
| car_battuta | `1.5 mm` | 1,5 | battuta dello sportellino sotto la pelle |
| car_puls_x | `-40 mm` | −40 | pulsante sull'asse, sopra lo zoccolo XBee della SSC-32 (fino a z 4,7: restano 9,7 mm sotto il corpo da 20) |
| car_puls_d | `12.2 mm` | 12,2 | foro del pulsante Ø12 (B3b) |
| cic_x0, cic_x1 | `-87 mm`, `-62 mm` | | cicalino 25 × 40 × 11 spostato di 1,8 indietro, pin verso la coda |
| cic_semi, cic_z0 | `20 mm`, `17.4 mm` | | |
| car_fin_l, car_fin_semi | `14 mm`, `12 mm` | | finestra del display centrata su (cic_x0 + cic_x1)/2 |
| car_guancia_x0 | `car_coda_x + 3.35 mm` | 100,5 | retro delle guance di coda, 1 mm dentro il lato del lobo posteriore a \|y\| 25,4 |
| car_guancia_x1 | `cor_tun_x0 + cor_sport_sp + 0.2 mm` | 87,6 | fronte delle guance, 0,2 dietro lo sportello della batteria |
| car_guancia_y0, car_guancia_y1 | `25.4 mm`, `cor_tun_semi` | 25,4; 27 | |
| car_guancia_giu | `cor_tetto - 1 mm` | 8,4 (z −8,4) | 1 mm sopra lo sportello, che si sfila sotto |
| car_occhio_x0 | `cor_cam_x + cam_alt + 0.9 mm` | 99,4 | bocca interna dell'occhio, 0,9 davanti alla lente |
| cam_fov_h, cam_fov_v | `54.2 deg`, `46.1 deg` | | semicampo, 120° in diagonale su sensore 4:3 (caso peggiore) |
| car_occhio_marg | `0.8 mm` | 0,8 | margine del campo |
| car_occhio_si | `cam_lente_d / 2 + (car_occhio_x0 - cor_cam_x - cam_alt) * tan(cam_fov_h) + car_occhio_marg` | 5,55 | |
| car_occhio_vi | come sopra con cam_fov_v | 5,24 | |
| car_occhio_se | `cam_lente_d / 2 + (car_viso_x - cor_cam_x - cam_alt) * tan(cam_fov_h) + car_occhio_marg` | 9,15 | |
| car_occhio_ve | come sopra con cam_fov_v | 7,94 | |
| car_bugna_semi, car_bugna_z0 | `11 mm`, `cor_cam_z - 7.5 mm` | 11; 15 | bugna dell'occhio dietro la visiera |

### 1.2 Zampa (nuovi, `zampa.py` → PARAMETRI)

| Nome | Espressione | Valore | Commento |
|---|---|---|---|
| cov_sp | `1.2 mm` | 1,2 | spessore delle cover |
| cov_ap | `14 mm` | 14 | semialtezza delle lame e apotema delle punte esagonali; il femore è ±13 |
| cov_punta | `cov_ap / cos(30 deg)` | 16,17 | raggio delle punte dai centri di anca e ginocchio: lama da X 38,83 a 136,17 |
| cov_fin_ap | `11 mm` | 11 | apotema delle finestre esagonali sui mozzi: teste delle squadrette fino a r 9,75, restano 1,25 mm d'aria |
| cov_yA0 | `zy_A_est + vite_m3_testa_h - cov_sp` | 32,35 | faccia interna della lama A; l'esterna sta a 33,55, a filo delle teste M3 |
| cov_gobba_c | `(fem_blocco_x0 + zam_Lf - fem_blocco_dk) / 2` | 32,75 | centro della gobba dall'anca (X 87,75) |
| cov_gobba_semi | `12.17 mm` | 12,17 | semibase della gobba a Z cov_ap; in cima 8,71 (fianchi a 60°) |
| cov_gobba_z | `fem_blocco_su` | 20 | cima della gobba |
| cov_testa_d | `5.6 mm` | 5,6 | sede sulle teste M3 ISO 4762 (dk 5,32…5,5); da tarare 5,4…5,7 sul provino |
| cov_tubo_D | `7.6 mm` | 7,6 | tubi della lama A attorno alle teste del blocco |
| cov_dist_d, cov_dist_u | `3 mm`, `15.2 mm` | | distanziali della lama A a X 70,2 e 104,8 |
| cov_spina_d, cov_spina_l | `3 mm`, `3 mm` | | spine della lama B |
| cov_foro_spina_d, cov_foro_spina_l | `3.1 mm`, `3.3 mm` | | fori ciechi in Femore_B: gioco nel modello, il forzamento lo dà la stampa (D-056) |
| cov_spina_z | `6 mm` | 6 | |
| gin_punta | `bug_coda` | 38,35 (Z −38,35) | punta della ginocchiera, alla base dello zoccolo |
| gin_lab | `1.8 mm` | 1,8 | labbro sulla cima della parete +X della culla |
| gin_tappo, gin_tappo_p | `cul_fin_lato - 0.4 mm`, `1.6 mm` | 11,6; 1,6 | tappi a rombo nelle finestre della culla |
| vite_m3_testa_d | `5.5 mm` | 5,5 | ingombro delle teste ISO 4762 |
| fem_fascetta_u | `24.5 mm` | 24,5 (X 79,5) | fascetta del femore dentro il blocco |
| fem_fascetta_fondo | `10 mm` | 10 | Z del tunnel della fascetta |

### 1.3 Cambiati
- **`_inserti_blocco`** (difetto di oggi: teste a interasse 5,4 contro dk 5,5, rondelle Ø7 sovrapposte di 1,6):
  - `ins_blocco_gb` da Z 7,5 a 6,0 (`z0 + ' + 1.5 mm'`);
  - `ins_blocco_ga` da 12,9 a 13,4 (`z1 + ' + 0.5 mm'`).
  
  Interasse 7,4: tra le rondelle restano 0,4 mm, tra le teste 1,9. Parete dell'inserto gb dallo smusso basso: 2,3 mm. Inserto ga: 4,5 mm dalla cima del blocco.
- **`cox_fascetta_x`** da 28 a 24 mm: la fascetta del ponte passa sotto il lobo e va montata con la testa di fianco al braccio.
- Restano invariati cor_cop_z (28,4), colonnine, base, vassoio, camera (asse a z 22,5, lente a x 98,5) e la sagoma delle zampe.

## 2. Corpo

### 2.1 Corpo_Carapace: nuovo, sostituisce Corpo_Coperchio. PETG bianco

**Forma.** Pianta: il contorno dell'unione di sei esagoni (R 32,3) sugli assi delle coxe, di un nucleo x −97,15…102 con \|y\| ≤ 30 e di un rettangolo \|x\| ≤ 80 con \|y\| ≤ 56. Semicontorno sinistro, dal centro del viso:

(102; 0), (102; 26,16), (112,30; 44), (96,15; 71,97), (63,85; 71,97), (54,63; 56), (27,68; 56), (16,15; 75,97), (−16,15; 75,97), (−27,68; 56), (−54,63; 56), (−63,85; 71,97), (−96,15; 71,97), (−112,30; 44), (−97,15; 17,76), (−97,15; 0).

Area 27 734 mm², perimetro 786, ingombro 224,6 × 151,9. Viso largo ±26,16, coda ±17,76.

Sezione:
- bordo verticale da z 28,4 a 30, poi smusso 6 × 45° fino alla faccia piana a z 36;
- dopo lo smusso la faccia piana misura 23 143 mm² e ha questi vertici: (96; 27,77), (105,37; 44), (92,69; 65,97), (67,31; 65,97), (58,09; 50), (24,22; 50), …

Testa sotto il carapace (x 82,6…102):
- fianchi verticali a \|y\| 25,2 da z 26,71 a 28,4;
- sotto, fianchi a 60° fino al mento \|y\| ≤ 9,2 a z −1;
- aperta sotto e dietro;
- la parete del viso (x 100,4…102, sotto z 28,4) è la visiera nera (2.3).

**Lavorazioni**, passo `carapace` in due chiamate, con `p = Parte(Corpo_Carapace)`.

*A. Testa (pieno), prima del carapace,* perché i tagli della rastremazione non intacchino i lobi:
1. `p.blocco('z', 'car_mento_z', 'testa', 'car_testa_x0', '-(car_testa_semi)', 'car_viso_x', 'car_testa_semi', 'cor_cop_z - car_mento_z', 1, NUOVO)`.
2. Rastremazione sinistra:
   `p.blocco_obl('x', 'car_testa_x0 - 1 mm', 'rastremazione_s', ('car_mento_semi', 'car_mento_z'), ('car_mento_semi + 10 mm * cos(car_rastr)', 'car_mento_z + 10 mm * sin(car_rastr)'), '-(5 mm)', '50 mm', '-(30 mm)', '0 mm', 'car_viso_x - car_testa_x0 + 2 mm', 1, TAGLIA)`.
   Nel piano 'x' si ha (u, v) = (y, z). b = a ruotato di +90° punta verso l'interno, quindi la parte tagliata è b < 0.
3. `p.specchia([rastremazione_s], 'y', 'rastremazione_d')`.

*B. Carapace pieno (UNISCI), da z cor_cop_z, alto `car_top - cor_cop_z`:*
4. `p.blocco('z', 'cor_cop_z', 'nucleo', '-(car_coda_x)', '-(car_testa_y)', 'car_viso_x', 'car_testa_y', 'car_top - cor_cop_z')`.
5. `p.blocco('z', 'cor_cop_z', 'baie', '-(cor_ang_x)', '-(car_valle_y)', 'cor_ang_x', 'car_valle_y', 'car_top - cor_cop_z')`.
6. Lobo AS, unione di tre rettangoli:
   - `p.blocco('z', 'cor_cop_z', 'lobo_as_0', 'cor_ang_x - car_lobo_R / 2', 'cor_ang_y - car_lobo_a', 'cor_ang_x + car_lobo_R / 2', 'cor_ang_y + car_lobo_a', 'car_top - cor_cop_z')`;
   - `p.blocco_obl('z', 'cor_cop_z', 'lobo_as_60', ('cor_ang_x', 'cor_ang_y'), ('cor_ang_x + 10 mm * cos(60 deg)', 'cor_ang_y + 10 mm * sin(60 deg)'), '-(car_lobo_R / 2)', 'car_lobo_R / 2', '-(car_lobo_a)', 'car_lobo_a', 'car_top - cor_cop_z')`;
   - la stessa a 120°.
7. Lobo MS: le stesse tre lavorazioni centrate su (0; cor_med_y).
8. `p.specchia([lobi AS], 'x', 'lobi_ps')`, poi `p.specchia([lobi AS, MS, PS], 'y', 'lobi_destri')`.

Controllo, in uno script a parte: la faccia a z = car_top ha area 27 734 ± 5 mm² e la pianta misura 224,6 × 151,9.

*C. Smusso:*
9. `p.smussa(spigoli del contorno esterno della faccia z = car_top, 'car_smusso', 'smusso')` (primitiva nuova, B0). È un solo valore: niente punti a due distanze. Controllo: la faccia piana misura 23 143 ± 10 mm².

*D. Svuotamento:*
10. `p.svuota([facce con normale −Z a z = cor_cop_z, faccia con normale −Z a z = car_mento_z, faccia con normale −X a x = car_testa_x0], 'car_sp', 'guscio')`.

Controllo: volume 53 ± 3 cm³. Lo stimo da 216,8 cm³ di pieno e dalle pareti da 1,6.

*E. Unioni (UNISCI), seconda chiamata:*

11. **Parte alta delle gonne (bianca, nascosta dal bordo delle valli).** `p.blocco('z', 'cor_cop_z', 'gonna_alta_as', 'cor_gonna_x0', 'cor_baia_y - cor_gonna_sp', 'cor_gonna_x1', 'cor_baia_y', 'car_top - car_sp - cor_cop_z')`, poi `specchia` su 'x' e su 'y'. La parte nera da z 7 a 28,4 è Corpo_Gonne (2.4).

12. **Paratie dietro la testa.** `p.blocco('z', 'cor_orlo', 'paratia_s', 'cor_tun_x1', 'car_paratia_y0', 'car_testa_x0', 'car_paratia_y1', 'car_top - car_sp - cor_orlo')` e lo specchio su 'y'. Chiudono il fronte del corpo sopra il muro anteriore della base, che arriva a z 7.

13. **Guance di coda.** `p.blocco('z', '-(car_guancia_giu)', 'guancia_s', '-(car_guancia_x0)', 'car_guancia_y0', '-(car_guancia_x1)', 'car_guancia_y1', 'car_top - car_sp + car_guancia_giu')` e lo specchio su 'y'.

14. **Pozzetti.** `p.cilindro('z', 'cor_cop_z', 'pozzo_tubo_a', 'cor_col_xa', 'cor_col_y', 'car_pozzo_D', 'car_top - car_sp - cor_cop_z')`, lo stesso a `-(cor_col_xp)` e gli specchi su 'y'.

15. **Collare del cicalino.**
    - Fianco: `p.blocco('z', 'cic_z0 + 8 mm', 'collare_s', 'cic_x0 - 0.2 mm', 'cic_semi + 0.2 mm', 'cic_x1 + 0.2 mm', 'cic_semi + 1.4 mm', 'car_top - car_sp - cic_z0 - 8 mm')` e il suo specchio.
    - Parete davanti: `p.blocco('z', 'cic_z0 + 8 mm', 'collare_fronte', 'cic_x1 + 0.2 mm', '-(14 mm)', 'cic_x1 + 1.4 mm', '14 mm', stessa altezza)`.
    - Due nervature di schiacciamento da 1 × 0,25 per fianco, a x −80 e −68.
    - Distanze: parete davanti a 0,9 dalle colonnine posteriori, fianchi a 1,1 dai tubi dei pozzetti. Il retro resta aperto per i pin.

16. **Battuta dello sportellino.** `p.blocco('z', 'car_top - 2 * car_sp', 'battuta', 'cor_serv_x0 - 1 mm', '-(car_serv_semi + 1 mm)', 'cor_serv_x1 + 1 mm', 'car_serv_semi + 1 mm', 'car_sp')`, poi il TAGLIA del rettangolo interno x da cor_serv_x0 + car_battuta a cor_serv_x1 − car_battuta, \|y\| ≤ car_serv_semi − car_battuta. Resta un passaggio \|y\| ≤ 14,5 sopra USB-C e pulsanti dell'ESP32.

*F. Tagli (TAGLIA):*

17. **Sede della fascia sul piano.** `p.blocco('z', 'car_top - car_fascia_h', 'sede_fascia', '-(car_coda_x - car_smusso)', '-(car_fascia_semi)', 'car_viso_x - car_smusso', 'car_fascia_semi', 'car_fascia_h', 1, TAGLIA)`.

18. **Sede sullo smusso del viso.** `p.blocco_obl('y', '-(car_fascia_semi)', 'sede_fascia_smusso_viso', ('car_viso_x', 'car_top - car_smusso'), ('car_viso_x - car_smusso', 'car_top'), '-(0.6 mm)', 'car_smusso * sqrt(2) + 0.6 mm', '-(1 mm)', 'car_fascia_h', '2 * car_fascia_semi', 1, TAGLIA)`. b positivo punta dentro il materiale.

19. **Sede sul bordo del viso, a piena parete.** `p.blocco('x', 'car_viso_x - car_sp', 'sede_fascia_bordo_viso', '-(car_fascia_semi)', 'cor_cop_z', 'car_fascia_semi', 'car_top - car_smusso', 'car_sp + 0.1 mm', 1, TAGLIA)`.

20. **Coda.**
    - Sullo smusso: `p.blocco_obl('y', '-(car_fascia_semi)', 'sede_fascia_smusso_coda', ('-(car_coda_x)', 'car_top - car_smusso'), ('-(car_coda_x - car_smusso)', 'car_top'), '-(0.6 mm)', 'car_smusso * sqrt(2) + 0.6 mm', '-(car_fascia_h)', '1 mm', '2 * car_fascia_semi', 1, TAGLIA)`. Qui b positivo punta fuori, quindi la sede è b < 0.
    - Sul bordo: `p.blocco('x', '-(car_coda_x)', 'sede_fascia_bordo_coda', '-(car_fascia_semi)', 'cor_cop_z', 'car_fascia_semi', 'car_top - car_smusso', 'car_fascia_h', 1, TAGLIA)`.

21. **Sede della visiera.** `p.blocco('x', 'car_viso_x - car_sp', 'sede_visiera', '-(car_testa_semi + 1 mm)', 'car_mento_z - 1 mm', 'car_testa_semi + 1 mm', 'cor_cop_z', 'car_sp + 0.1 mm', 1, TAGLIA)`. Toglie la parete del viso e gli ultimi 1,6 mm dei fianchi rastremati: la visiera li sostituisce.

22. **Apertura di servizio (ottagono).**
    - `p.blocco('z', 'car_top - car_sp', 'apertura_a', 'cor_serv_x0', '-(car_serv_semi - car_serv_smusso)', 'cor_serv_x1', 'car_serv_semi - car_serv_smusso', 'car_sp', 1, TAGLIA)`.
    - `p.blocco(… 'apertura_b', 'cor_serv_x0 + car_serv_smusso', '-(car_serv_semi)', 'cor_serv_x1 - car_serv_smusso', 'car_serv_semi', …)`.
    - 4 `blocco_obl` TAGLIA d'angolo. Ognuno ha un lato sulla retta a 45° fra (x1 − 6; 16) e (x1; 10) e va verso l'interno di `car_serv_smusso * sqrt(2) / 2`. Gli angoli del rettangolo così stanno tutti dentro l'ottagono.
    - Vertici dell'ottagono: (−14; ±16), (22; ±16), (28; ±10), (−20; ±10).

23. **Feritoie.** I 10 tagli di oggi (`_x_feritoia(i)`, \|y\| da cor_fer_y − 1,5 a +1,5), solo nella pelle: da `car_top - car_sp`, alti `car_sp`. Stanno fuori dalla fascia.

24. **Pozzetti.** `p.cilindro('z', 'cor_cop_z + cor_cop_sp', 'pozzo_vano_..', x, y, 'car_pozzo_d', 'car_top - cor_cop_z - cor_cop_sp', 1, TAGLIA)` e `p.cilindro('z', 'cor_cop_z', 'pozzo_foro_..', x, y, 'vite_m3_pass', 'cor_cop_sp', 1, TAGLIA)`, nei 4 punti delle colonnine.

25. **Pulsante.** `p.cilindro('z', 'car_top - car_sp', 'foro_pulsante', 'car_puls_x', '0 mm', 'car_puls_d', 'car_sp', 1, TAGLIA)`.

26. **Finestra del display.** `p.blocco('z', 'car_top - car_sp', 'finestra_cicalino', '(cic_x0 + cic_x1) / 2 - car_fin_l / 2', '-(car_fin_semi)', '(cic_x0 + cic_x1) / 2 + car_fin_l / 2', 'car_fin_semi', 'car_sp', 1, TAGLIA)`.

27. **Tacca dell'unghia.** `p.blocco('z', 'car_top', 'tacca', 'cor_serv_x1 + 1 mm', '-(5 mm)', 'cor_serv_x1 + 4 mm', '5 mm', '0.8 mm', -1, TAGLIA)`.

L'occhio si taglia nella visiera e nella fascia (2.2, 2.3). Nel carapace il tronco di piramide non incontra materiale: le sedi 19 e 21 lo hanno già tolto.

**Fissaggio.** Come oggi (D-052): 4 viti M3 × 8 negli inserti delle colonnine. La sede del pozzetto (z 28,4…30) appoggia sulla colonnina: 1,6 di sede più 6,4 nell'inserto. La testa resta da 1,6 a 3 mm sotto la superficie. Le gonne appoggiano sull'orlo delle baie (z 7).

**Togliere il carapace.** Si toglie verso l'alto, come oggi. Prima si staccano lo spinotto di bilanciamento, dal retro, e il Dupont a 2 vie del pulsante (C4). Il cicalino e il pulsante salgono con il carapace.

**Stampa.** Un solo pezzo multimateriale con Fascia, Visiera e Gonne: PETG bianco più PETG nero, sulla Creator 5 Pro.
- Orientamento: capovolto, faccia z 36 sul PEI testurizzato. Ingombro 224,6 × 151,9 × 44,4 (le guance scendono a z −8,4).
- Supporti: nessuno.
  - Ponti: fondo dei pozzetti Ø7 e battuta da 1,5.
  - Occhio: la parete bassa è a 43° dalla verticale.
  - Testa: i fianchi a 60° e lo smusso a 45°, a pezzo capovolto, guardano in alto.
- Cambi di testina: circa 180, negli strati da 1,6 a 37 mm dove ci sono visiera e gonne. Con il toolchanger, da 30 a 60 minuti in più.
- Brim e piatto caldo. Area utile con lo spurgo da confermare (D-050).

### 2.2 Corpo_Fascia: nuovo, PETG nero. Un corpo, intarsio a filo

Corrisponde alle sedi 17–20 del carapace. Lavorazioni:

1. **Piano.** `p.blocco('z', 'car_top - car_fascia_h', 'fascia', '-(car_coda_x - car_smusso)', '-(car_fascia_semi)', 'car_viso_x - car_smusso', 'car_fascia_semi', 'car_fascia_h', 1, NUOVO)`.

2. **Smusso del viso.** `p.blocco_obl('y', '-(car_fascia_semi)', 'fascia_smusso_viso', ('car_viso_x', 'car_top - car_smusso'), ('car_viso_x - car_smusso', 'car_top'), '0 mm', 'car_smusso * sqrt(2)', '0 mm', 'car_fascia_h', '2 * car_fascia_semi')`. Ho verificato in pianta che i tre pezzi coprono la sede senza vuoti.

3. **Bordo del viso, a piena parete.** `p.blocco('x', 'car_viso_x - car_sp', 'fascia_bordo_viso', '-(car_fascia_semi)', 'cor_cop_z', 'car_fascia_semi', 'car_top - car_smusso', 'car_sp')`.

4. **Coda.** `p.blocco_obl` come la sede 20 (a da 0 a `car_smusso * sqrt(2)`, b da `-(car_fascia_h)` a 0) e `p.blocco('x', '-(car_coda_x)', 'fascia_bordo_coda', …, 'car_fascia_h')`.

5. **Fori**, con le stesse espressioni del carapace: apertura ottagonale (22), pulsante (25), finestra (26), tacca (27).

6. **Occhio**, cinque tagli (vedi 2.3, punto 4). Tolgono la parte del tronco fra z 28,4 e 30,44.

In vista: la fascia corre sulla schiena, scende sul viso fino a z 28,4, dove continua nella visiera, e sulla coda fino al bordo sopra la porta.

### 2.3 Corpo_Visiera: nuova, PETG nero. Alloggiamento della camera, integrato nel frontale e stampato insieme al carapace

1. **Lastra.** `p.blocco('x', 'car_viso_x - car_sp', 'visiera', '-(car_testa_semi)', 'car_mento_z', 'car_testa_semi', 'cor_cop_z', 'car_sp', 1, NUOVO)`.

2. **Rastremazione.** Le stesse due lavorazioni del punto A2–A3 del carapace, sul corpo della visiera.

3. **Bugna.** `p.blocco('x', 'car_occhio_x0', 'bugna_occhio', '-(car_bugna_semi)', 'car_bugna_z0', 'car_bugna_semi', 'cor_cop_z', 'car_viso_x - car_sp - car_occhio_x0')`, in UNISCI.

4. **Occhio, tronco di piramide con quattro tagli piani.** È la riserva provata; lo smusso a due distanze non serve.
   - Foro: `p.blocco('x', 'car_occhio_x0', 'occhio_foro', '-(car_occhio_si)', 'cor_cam_z - car_occhio_vi', 'car_occhio_si', 'cor_cam_z + car_occhio_vi', 'car_viso_x - car_occhio_x0 + 1 mm', 1, TAGLIA)`.
   - Pareti laterali: `p.blocco_obl('z', 'cor_cam_z - car_occhio_ve - 1 mm', 'occhio_fianco_s', ('car_occhio_x0', 'car_occhio_si'), ('car_viso_x', 'car_occhio_se'), '-(1 mm)', '6 mm', '-(10 mm)', '0 mm', '2 * car_occhio_ve + 2 mm', 1, TAGLIA)` e lo specchio su 'y'.
   - Pareti alta e bassa: due `blocco_obl` su 'y', con estrusione lungo y da `-(car_occhio_se + 1 mm)` per `2 * car_occhio_se + 2 mm`. Quella alta va da (car_occhio_x0; cor_cam_z + car_occhio_vi) a (car_viso_x; cor_cam_z + car_occhio_ve). Quella bassa è simmetrica rispetto a z = cor_cam_z.

**Geometria dell'occhio.** Bocca interna 11,1 × 10,5 a x 99,4; bocca esterna 18,3 × 15,9 a x 102. Le pareti sono sul campo più 0,8 mm (54,2° e 46,1°).

**Verifica del campo** (verifiche.py, raggi da tutto il bordo della lente Ø7, obiettivo rettilineo 120°):
- margine minimo 0,80 mm;
- lo spigolo fra viso e smusso (102; 30) è a 48,8° in verticale, contro 46,1° di campo;
- le corna (112,3; 44) sono a 71,2°, contro 54,2°;
- la bocca esterna arriva a z 30,44 e intacca lo smusso di 0,44 mm, sopra il campo (accettato);
- le ginocchia anteriori restano al bordo dell'immagine, come in D-057.

**Montaggio della camera.** Invariato: torretta e mensola del vassoio, lente a x 98,5, flat sopra la torretta. La visiera sta a x ≥ 99,4, quindi il carapace si sfila senza toccare la camera. Le pareti dell'occhio, nere, tolgono i riflessi.

### 2.4 Corpo_Gonne: nuovo, PETG nero. 4 corpi

Quattro blocchi NUOVO: `p.blocco('z', 'cor_orlo', 'gonna_as', 'cor_gonna_x0', 'cor_baia_y - cor_gonna_sp', 'cor_gonna_x1', 'cor_baia_y', 'cor_cop_z - cor_orlo', 1, NUOVO)` e gli altri tre (x negative, y negative).

Toccano la parte alta bianca (punto 11) a z 28,4 e appoggiano sull'orlo delle baie. Stanno 6 mm dentro il bordo delle valli, quindi di lato sotto il guscio si vede solo scuro. Volume 3,78 cm³.

### 2.5 Corpo_Sportello_Servizio: rifatto, PETG nero

`fai_sportellino` riscritto:
- lastra a filo, `p.blocco('z', 'car_top - car_sp', 'piastra', 'cor_serv_x0 + 0.2 mm', '-(car_serv_semi - 0.2 mm)', 'cor_serv_x1 - 0.2 mm', 'car_serv_semi - 0.2 mm', 'car_sp', 1, NUOVO)`;
- 4 tagli d'angolo a 45° come il punto 22, spostati di 0,2 verso l'interno;
- 4 nervature di schiacciamento larghe 1 sui lati lunghi, a x 16 e −8, a filo dell'apertura (D-056).

Appoggia sulla battuta e resta su per attrito. Volume circa 2,4 cm³ (4 g). Stampa: faccia in vista sul PEI.

### 2.6 Corpo_Sportello (della batteria): PETG bianco

Geometria e viti invariate (D-054). In più, smusso 1 × 45° sui quattro spigoli esterni della piastra, con `p.smussa`, oppure 4 `blocco_obl` TAGLIA. Insieme alle guance fa la cornice bianca della porta di servizio. Stampa: faccia esterna sul PEI.

### 2.7 Comprati: cicalino e pulsante

**Ingombro del pulsante.** In `rif_componenti.py` si aggiunge l'ingombro `Rif_Pulsante_12`. Origine al centro della faccia superiore del pannello, +Z in alto:
- flangia Ø15 × 2 (z 0…2);
- corpo Ø12 da z −21,6 a 0;
- dado Ø17,3 × 2 da z −3,6 a −1,6.

**Istanze in `assieme.py` → `pose_corpo`:**
- `out['Cicalino'] = ('Rif_Cicalino_BX100', _rz((cic_x0 + cic_x1) / 2, 0, cic_z0, 90.0))`. Il box 40 × 25 × 11 ha il lato da 40 lungo y e i pin verso −X.
- `out['Pulsante'] = ('Rif_Pulsante_12', _rz(car_puls_x, 0, car_top, 0.0))`.

Il cicalino oggi è solo in libreria: va aggiunto. Il pulsante occupa z 14,4…38: a −40 sotto ci sono 9,7 mm sopra lo zoccolo XBee.

## 3. Zampa

### 3.1 Femore_B e Femore_A

**Inserti del blocco.** Nuove posizioni (1.3): Femore_B (inserti) e Femore_A (fori) si rigenerano.

**Fori ciechi per le spine della lama B**, in `fai_femore_b`: `p.cilindro('y', 'zy_B_est', 'foro_spina_a', 'zam_Lc + fem_blocco_x0 + fem_ins_dx', 'cov_spina_z', 'cov_foro_spina_d', 'cov_foro_spina_l', 1, TAGLIA)` e lo stesso a `'zam_Lc + zam_Lf - fem_blocco_dk - fem_ins_dx'`. Sono a X 81 e 94,5, Z 6: nella piastra B e nel blocco, lontani dagli inserti, che stanno sul lato A (Y 20,45…27,15).

**Fascetta del femore dentro il blocco.** D-058 cambia: prima la fascetta da 200 mm girava attorno al femore. Ora è una fascetta corta da 2,5 mm (D11) in due feritoie e un tunnel:
- `p.blocco('z', 'fem_fascetta_fondo', 'feritoia_femore_a', 'zam_Lc + fem_fascetta_u - fascetta_w / 2', 'cox_fascetta_y - fascetta_sp / 2', 'zam_Lc + fem_fascetta_u + fascetta_w / 2', 'cox_fascetta_y + fascetta_sp / 2', 'fem_blocco_su - fem_fascetta_fondo', 1, TAGLIA)`;
- la gemella a \|y\| negative;
- il tunnel: `p.blocco('z', 'fem_fascetta_fondo', 'tunnel_femore', stessi x, '-(cox_fascetta_y + fascetta_sp / 2)', 'cox_fascetta_y + fascetta_sp / 2', 'fascetta_sp', 1, TAGLIA)`.

L'anello sta sullo smusso alto del blocco, fra le piastre: non si vede dai lati e non tocca le cover.

Risolve anche il difetto di oggi (la fascetta a 15 mm dall'anca entra nella testa dell'anima da α 74°). Ad α 85 l'anello sta a X 38,2, Z circa 26: 6 mm sopra la testa dell'anima, 2,5 mm sopra il ponte, fuori dal lobo.

### 3.2 Coxa_Ponte
Si cambia cox_fascetta_x a 24 e si rigenera il ponte. La testa della fascetta va di fianco al braccio. Sotto la pelle del carapace (z 34,4) restano 8 mm.

### 3.3 Ingombro_Teste_A: nuovo, non stampato, 12 corpi

Teste ISO 4762 sul lato A, per verificare le zampe vicine e le sedi della lama. `p.cilindro('y', 'zy_A_est', nome, x, z, 'vite_m3_testa_d', 'vite_m3_testa_h', 1, NUOVO)`:
- 8 sulle squadrette: (xc ± sq_fori_pcd/2; 0) e (xc; ±sq_fori_pcd/2), con xc = zam_Lc e zam_Lc + zam_Lf;
- 4 sul blocco, nelle posizioni di `_inserti_blocco()`.

Volume 855,3 mm³. Va escluso da masse ed esportazioni.

### 3.4 Cover_Femore_A: lama sospesa, PETG bianco

Lastra 1,2 da Y 32,35 a 33,55. La faccia esterna sta a filo delle teste M3, quindi la zampa non si allarga. Sotto resta una fuga d'ombra di 1,8 mm.

Sagoma nel piano X–Z:
- punte esagonali sui mozzi, con vertici a X 38,83 e 136,17;
- lati a Z ±14;
- gobba sopra il blocco, da (75,58; 14) a (79,04; 20), piatta a Z 20 fino a 96,46, poi fino a (99,92; 14).

Due finestre esagonali (apotema 11, vertici lungo X) sui mozzi di anca e ginocchio. Dentro si vedono le 8 teste delle squadrette e il foro d'accesso Ø6.

Lavorazioni, sul piano 'y' a `cov_yA0`, verso +1:
1. Corpo: `p.blocco('y', 'cov_yA0', 'corpo', 'zam_Lc', '-(cov_ap)', 'zam_Lc + zam_Lf', 'cov_ap', 'cov_sp', 1, NUOVO)`.

2. Punte. Per xc in (zam_Lc, zam_Lc + zam_Lf), tre rettangoli:
   - `p.blocco('y', 'cov_yA0', 'punta0_..', xc − cov_punta/2, −cov_ap, xc + cov_punta/2, cov_ap, 'cov_sp')`;
   - `p.blocco_obl('y', 'cov_yA0', 'punta60_..', (xc, '0 mm'), (xc + ' + 10 mm * cos(60 deg)', '10 mm * sin(60 deg)'), '-(cov_punta / 2)', 'cov_punta / 2', '-(cov_ap)', 'cov_ap', 'cov_sp')`;
   - la stessa a 120°.

3. Gobba: `p.blocco('y', 'cov_yA0', 'gobba', 'zam_Lc + cov_gobba_c - cov_gobba_semi', 'cov_ap - 1 mm', 'zam_Lc + cov_gobba_c + cov_gobba_semi', 'cov_gobba_z', 'cov_sp')`.

4. Fianchi della gobba, due `blocco_obl` TAGLIA:
   - fianco verso l'anca: p0 = (zam_Lc + cov_gobba_c − cov_gobba_semi; cov_ap), p1 a +60°, a da 0 a 20, b da 0 a 20;
   - fianco verso il ginocchio: p0 = (… + cov_gobba_semi; cov_ap), p1 a +120°, a da 0 a 20, b da −20 a 0.
   
   Con a0 = 0 i tagli non scendono sotto Z 14.

5. Finestre: per ogni xc, tre TAGLIA come il punto 2, con semiasse `cov_fin_ap / cos(30 deg) / 2` (6,35) e apotema `cov_fin_ap`.

6. Tubi: `p.cilindro('y', 'zy_A_est', 'tubo_..', x, z, 'cov_tubo_D', 'cov_yA0 - zy_A_est')`, nelle 4 posizioni di `_inserti_blocco()`. I due tubi gb e ga si fondono: interasse 7,4 contro Ø7,6.

7. Distanziali: `p.cilindro('y', 'zy_A_est', 'distanziale_anca', 'zam_Lc + cov_dist_u', '0 mm', 'cov_dist_d', 'cov_yA0 - zy_A_est')` e lo stesso a `zam_Lc + zam_Lf - cov_dist_u`.

8. Sedi: `p.cilindro('y', 'zy_A_est', 'sede_..', x, z, 'cov_testa_d', 'cov_yA0 + cov_sp - zy_A_est', 1, TAGLIA)` nelle 4 posizioni.

9. Facoltativo: `p.smussa` 0,6 sul contorno della faccia esterna, se B0 ha provato la primitiva.

Pareti minime:
- dai fianchi della gobba ai tubi: 1,44 mm verso l'anca e 1,19 verso il ginocchio;
- fra i tubi ab e aa: 0,8.

Volume circa 2,20 cm³, 2,8 g.

**Fissaggio.** A pressione sulle 4 teste M3 × 8 del blocco: 3 mm di presa per testa, i tubi poggiano sulla piastra A. Nessuna vite in più. Si toglie tirando. Le viti delle squadrette restano raggiungibili dalle finestre.

**Stampa.** Faccia esterna sul PEI; tubi e distanziali in alto; senza supporti.

### 3.5 Cover_Femore_B: lama appoggiata, PETG bianco

Stessa sagoma, stessa gobba e stesse finestre, sul piano `zy_B_est` verso −1: lastra da Y −30,55 a −31,75, dentro la sporgenza dei perni (−31,95). Nelle finestre si vede la testa del perno, 0,2 mm sopra la lama.

Le spine: `p.cilindro('y', 'zy_B_est', 'spina_..', x, 'cov_spina_z', 'cov_spina_d', 'cov_spina_l', 1)`, a X 81 e 94,5, verso +Y dentro i fori ciechi.

Volume circa 2,19 cm³, 2,8 g. Stampa: faccia esterna sul PEI, spine in alto.

Il lato B ha lo stesso peso visivo del lato A (stessa sagoma bianca, due finestre scure). Le zampe destre e sinistre, che non sono specchiate, da davanti si leggono uguali.

### 3.6 Cover_Tibia: ginocchiera a scudo, PETG bianco

Sostituisce lo schiniere di Kabuto. Sta solo sulla faccia +X della culla del ginocchio, da X 132,45 a 133,65: niente piega sullo stinco, quindi niente compenetrazione.

Sagoma nel piano Y–Z:
- da Y −24,15 a 9,45 e da Z 13,65 in giù;
- lati dritti fino a Z −9,25, poi punta a 60° in (−7,35; −38,35).

Il servo sopra l'orlo resta a vista, come giunto scuro. Area 1258 mm², contro 2280 dello schiniere di Kabuto: la lama del femore torna l'elemento più grande.

Lavorazioni, con xk = `zam_Lc + zam_Lf`:
1. `p.blocco('x', xk + ' + cul_semi', 'piastra', 'zy_fondo_est', '-(gin_punta)', 'zy_orlo', 'cul_corto + cov_sp', 'cov_sp', 1, NUOVO)`.
2. Labbro: `p.blocco('z', 'cul_corto', 'labbro', xk + ' + cul_semi - gin_lab', 'zy_fondo_est', xk + ' + cul_semi + cov_sp', 'zy_orlo', 'cov_sp')`. Sta fuori dalle bugne (X ≤ 128,7) e dalla fessura del cavo.
3. Tappi: `p.blocco_obl('x', xk + ' + cul_semi', 'tappo_1', ('cul_fin_y', '-(cul_fin_z1)'), ('cul_fin_y + 1 mm', '-(cul_fin_z1) + 1 mm'), '-(gin_tappo / 2)', 'gin_tappo / 2', '-(gin_tappo / 2)', 'gin_tappo / 2', 'gin_tappo_p', -1)` e lo stesso con cul_fin_z2. È la stessa chiamata delle finestre di `_alleggerisci_culla`. Dietro il tappo restano 0,6 mm fino al servo.
4. Punta, dopo i tappi (così il taglio rifila anche il tappo basso, 0,25 mm), due `blocco_obl` TAGLIA:
   - piano 'x' a `xk + ' + cul_semi - gin_tappo_p - 0.5 mm'`, alti `gin_tappo_p + cov_sp + 1 mm`;
   - p0 = ('(zy_fondo_est + zy_orlo) / 2', '-(gin_punta)');
   - p1 a 120° per il lato −Y (b da 0 a 30), a 60° per il lato +Y (b da −30 a 0); a da −5 a 40.

Volume circa 2,0 cm³, 2,6 g.

**Fissaggio.** Labbro più 2 tappi a rombo a pressione; nessuna vite.

**Stampa.** Faccia esterna sul PEI, labbro e tappi in alto.

**Movimento.** Sta tutta sulla faccia esterna:
- a γ 180 il labbro è a u 51,35 dal blocco (che finisce a 44), e la lastra (\|Y\| ≤ 24,15) resta dentro le piastre del femore e lontana dalla squadretta (Y ≥ 21,85);
- la tabella del γ minimo non cambia;
- la punta è 71,7 mm sopra il piede.

### 3.7 Giunti e pose

**`zampa.py`:**
- RIGIDI += ('R_cover_femore_a', 'Cover_Femore_A', 'Femore_A'), ('R_cover_femore_b', 'Cover_Femore_B', 'Femore_B'), ('R_cover_tibia', 'Cover_Tibia', 'Tibia'), ('R_teste_a', 'Ingombro_Teste_A', 'Femore_A');
- passi nuovi: `teste_a`, `cover_femore_a`, `cover_femore_b`, `cover_tibia`.

**`assieme.py`:**
- SEGUONO_FEMORE = ('Femore_B', 'Femore_A', 'Cover_Femore_A', 'Cover_Femore_B', 'Ingombro_Teste_A');
- SEGUONO_TIBIA = ('Tibia', 'Cover_Tibia').

Senza questa modifica `posa_zampa` lascia ferme le cover e il ciclo dà falsi urti o falsi via libera.

Ogni componente nuovo ha una sola istanza nella Zampa: `_istanze` e `_gruppo` funzionano per nome.

## 4. Librerie e assieme (blocco B0)

**`lib_cad.Parte`:**
- `smussa(spigoli, dist_expr, nome)`, con chamferFeatures a distanza uguale e catena tangente spenta;
- `spigoli_contorno(corpo, asse, quota)`: gli spigoli del contorno esterno della faccia piana a quella quota.

Da provare prima in un documento di prova: un pieno con due esagoni da tre rettangoli e una valle concava, smusso 6, svuotamento 1,6 togliendo il fondo. Controllo: volume contro il conto a mano e rigenerazione cambiando un parametro.

**`lib_assieme.sentinella`:**
- accetta {nome: (volume_mm3, corpi)}, per i componenti a più corpi (Corpo_Gonne 4, Ingombro_Teste_A 12);
- `massa_e_baricentro` somma tutti i corpi.

**`assieme.py`:**
- VOLUMI_ATTESI, che oggi non esiste: si legge da `stato` in B0 e si aggiorna dopo ogni blocco solo per i pezzi cambiati;
- passi nuovi: `vicine`, `carapace_zampe`, `sfilamento`, `campo` (sezione 5).

## 5. Verifiche in Fusion

Ogni verifica in una chiamata a parte, con il suo caso di controllo.

1. **Zampa, dopo B1–B3.**
   - `stato`: schizzi vincolati. Volumi: Cover_Femore_A circa 2,20 cm³, B circa 2,19, Cover_Tibia circa 2,0, Ingombro_Teste_A 0,855, Femore_B circa −0,13 cm³ rispetto a oggi, Femore_A invariato.
   - `controllo` = 0,000; `giunti`, `limiti`, `calibra`; `misura` = (0; 90).
   - `interferenze` nella posa di riferimento: nessuna. Teste contro tubi: luce 0,05; teste e distanziali appoggiati.
   - `scansione`:
     - α da −49 a +85 a passi di 5, con γ 90: libera;
     - per ogni α di GAMMA_MIN, γ al minimo: libera, e γ − 2 tocca come oggi (tabella invariata);
     - γ 180 con α −49, 0, +85: libera.
   - Controllo: α −50 dà il contatto piastra-culla di oggi.

2. **Assieme, posa di riferimento.** Nessuna interferenza. Le coxe a ±20 e ±35, una zampa alla volta: libere.

3. **Zampe vicine** (`vicine`; verso dei giunti da verificare prima con AS +10).
   - Coppie AS–MS, MS–PS (AS +ψ, MS −ψ; MS +ψ, PS −ψ) e le destre: a 31° libere. Si registra l'angolo di contatto a 32, 33 e 34. Nel modello in pianta il contatto è a 31,5° (oggi 31,7), con 1,88 mm a 31° e 5,78 a 30°.
   - AS–AD e PS–PD: a 34° libere (in pianta contatto a 34,9).
   - Controllo: a 40° deve toccare.

4. **Carapace contro le zampe** (`carapace_zampe`, una zampa per chiamata).
   - `posa_zampa` con imbardata −35, 0, +35 e (α, γ) = (85, 90), (85, 29), (60, 90). Interferenze solo fra il gruppo del carapace (Carapace, Fascia, Visiera, Gonne) e la zampa atteggiata.
   - measureMinimumDistance fra il carapace e Femore_A, Femore_B, Cover_Femore_A e B: attesi almeno 3,4 mm (MS a +35° nella valle tra PS e MS) e almeno 4,3 nella valle tra AS e MS.
   - Controllo: α 100 deve dare urto con il carapace.

5. **Testa.** AS e AD a −35° con α −49, 0, +85: liberi dalla testa (la punta della lama resta circa 14 mm davanti al viso). Il viso avanza di 1 mm rispetto a oggi: controllare la distanza dalla lente (0,9 mm).

6. **Ciclo a tripode.**
   - 100/45 e 130/25 in 4 fasi; 80/60 e 70/70 in 16 fasi: nessun urto.
   - Giro a 100/45 e a 70/70, 8 fasi: nessun urto.
   - Controllo: quelli di oggi (femore −60°, vicine a 40°).

7. **Sfilamento** (`sfilamento`).
   - `transform2` = traslazione in z sui proxy dalla radice di Corpo_Carapace, Corpo_Fascia, Corpo_Visiera, Corpo_Gonne, Corpo_Sportello_Servizio, Cicalino e Pulsante.
   - +5, +10, +20, +40 mm: nessuna interferenza. Poi `ripristina`.
   - Controllo: −2 mm, le gonne urtano l'orlo delle baie.

8. **Campo della camera** (`campo`).
   - Componente provvisorio: tronco di piramide da un quadrato 7 × 7 a x 98,5 con 54,2° e 46,1°, lungo 15 mm. Si fa con un blocco e 4 `blocco_obl` TAGLIA.
   - Interferenza con Visiera, Fascia e Carapace = 0. Poi si cancellano il componente e il suo gruppo in timeline e si ricontrolla la sentinella.
   - Controllo: con +6° sui due angoli deve toccare le pareti dell'occhio.

9. **Chiusura.** Sentinella con tutte le altre parti invariate; timeline senza avvisi e senza lavorazioni orfane, dopo la cancellazione di Corpo_Coperchio; nessuna posa pendente.

## 6. Stampa e materiali

| Pezzo | Materiale | Orientamento | Supporti | Massa |
|---|---|---|---|---|
| Carapace con Fascia, Visiera e Gonne | PETG bianco e PETG nero, un solo pezzo multimateriale | capovolto, faccia z 36 sul PEI | nessuno | circa 77 g (60 bianco, 17 nero) |
| Sportellino di servizio | PETG nero | faccia sul PEI | no | 4 g |
| Sportello della batteria | PETG bianco | faccia esterna sul PEI | no | 7 g (invariata) |
| Cover_Femore_A × 6 | PETG bianco | faccia sul PEI, tubi in alto | no | 2,8 g |
| Cover_Femore_B × 6 | PETG bianco | faccia sul PEI, spine in alto | no | 2,8 g |
| Cover_Tibia × 6 | PETG bianco | faccia sul PEI, labbro e tappi in alto | no | 2,6 g |
| Piedini (D9) | TPU 95A arancio | punta in alto | no | invariata |

PETG e non PLA, per il calore di servo e regolatori e per le cadute. Esportazione:
- il carapace in 3MF con i quattro componenti (Carapace, Fascia, Visiera, Gonne) come corpi separati; se l'API non lo fa, STL separati e materiale assegnato per oggetto nello slicer;
- Ingombro_Teste_A non si esporta.

**Provino prima delle parti vere:** tubo Ø5,4/5,6/5,7 su una testa M3, spina Ø2,9/3,0/3,1 nel foro, tappo a rombo, nervature dello sportellino, collare del cicalino.

## 7. Massa e statica
- Carapace: +25 g (81 contro i 56 di coperchio, muso e sportellino di oggi).
- Cover: 8,2 g a zampa, 49 g in tutto.
- Totale: **+74 g**, cioè circa 2805 g attesi, 55 g sopra i 2750 di progetto.

`calc/statica_tripode.py` con massa 2810 g: femore al 49 % dello stallo (48 % a 2750), ginocchio al 45 % (44 %). Restano sotto il 50 %.

## 8. Documenti (B8)
- D-060 in `decisioni.md`.
- D-058 aggiornata: fascetta del femore nel blocco, fascetta del ponte a X 24.
- `progetto-meccanico.md`: parti nuove, verifiche, tabella delle masse.
- BOM: E2 PETG bianco, PETG nero non caricato, E3 TPU arancio, da approvare; viteria invariata; fascetta del femore corta.
- `CLAUDE.md`: stato e mappa della repo.
- `calc/verifiche_estetica.py`, dal file dei conti.

## Blocchi di lavoro

- B0 — Preparazione. Salvare una versione del design. Leggere `stato` e scrivere VOLUMI_ATTESI in assieme.py. Aggiungere Parte.smussa e spigoli_contorno e adattare sentinella e massa ai componenti a più corpi. Provare smusso a 6 su valli concave più svuotamento in un DOCUMENTO DI PROVA, controllando il volume a mano. Verifica: il design non cambia (sentinella 'invariati').
- B1 — Zampa, struttura. Parametri nuovi. _inserti_blocco (gb Z 6,0, ga Z 13,4). Fori delle spine e fascetta nel blocco di Femore_B. cox_fascetta_x 24. Rigenerare ponte, femore_b e femore_a; nuovo Ingombro_Teste_A. Poi giunti, limiti, calibra, misura (0; 90), controllo, interferenze, scansione (tabella del γ minimo invariata). Assieme: interferenze, coxe ±35, vicine a 31–34 come riferimento con le teste vere (in pianta 31,7°).
- B2 — Cover del femore. fai_cover_femore_a (sospesa a 32,35…33,55, tubi sulle teste del blocco) e fai_cover_femore_b (appoggiata, spine). RIGIDI e SEGUONO_FEMORE. Zampa: stato (volumi circa 2,20 e 2,19 cm³), giunti, misura, interferenze, scansione. Assieme: coxe, vicine (31° libere, contatto in pianta 31,5°), ciclo 70/70.
- B3 — Ginocchiera. fai_cover_tibia (piastra, labbro, tappi, poi i tagli della punta), RIGIDO, SEGUONO_TIBIA. Zampa: interferenze e scansione del ginocchio (γ minimo e γ 180). Assieme: ciclo 100/45 e 70/70.
- B4 — Carapace, guscio. Salvare una versione. Cancellare Corpo_Coperchio e il vecchio Corpo_Sportello_Servizio, una occorrenza alla volta, poi le lavorazioni orfane. Parametri del corpo. Passi A–D (testa e rastremazione, nucleo, baie, sei lobi, smusso, svuotamento) in una chiamata. In una chiamata a parte: stato (volume 53 ± 3 cm³, faccia piana 23 143 mm², ingombro 224,6 × 151,9), sentinella, interferenze dell'assieme.
- B5 — Carapace, dettagli. Unioni (gonne alte, paratie, guance, pozzetti, collare, battuta), poi tagli (sedi di fascia e visiera, ottagono di servizio, feritoie, pozzetti, pulsante, finestra, tacca), in due chiamate. Stato, schizzi vincolati, sentinella, interferenze nella posa di riferimento.
- B6 — Pezzi neri e sportelli. Corpo_Fascia, Corpo_Visiera (con bugna e i 5 tagli dell'occhio, ripetuti nella fascia), Corpo_Gonne (4 corpi), Corpo_Sportello_Servizio rifatto, smusso dello sportello della batteria. Verifica: volumi (fascia circa 3,0, visiera circa 1,6, gonne 3,78, sportellino circa 2,4 cm³) e nessuna interferenza fra carapace e pezzi neri, che si toccano soltanto.
- B7 — Comprati e assieme completo. Rif_Pulsante_12 in rif_componenti.py; Cicalino e Pulsante in pose_corpo. istanze_corpo e controllo. Poi verifiche 2–9 della specifica, ognuna con il suo caso di controllo: interferenze, coxe, vicine, carapace contro zampe ad α 85, testa, ciclo e giro, sfilamento, campo della camera.
- B8 — Chiusura. Masse da stato, poi statica_tripode.py con la massa nuova (femore ≤ 50 %). STL e 3MF multimateriale del carapace. D-060, D-058 aggiornata, progetto-meccanico.md, BOM (colori dei filamenti da approvare), CLAUDE.md. Conti in calc/. Provino delle ritenute a pressione prima di stampare le 18 cover e il carapace.

## Verifiche

- Zampa, posa di riferimento: nessuna interferenza, con le teste M3 modellate (Ingombro_Teste_A); misura (0; 90); trasformate delle istanze con scarto 0,000.
- Scansione della zampa con i giunti veri: femore libero da −49 a +85 (controllo: −50 tocca); tabella del γ minimo identica a quella di oggi; γ 180 libero con α −49, 0, +85.
- Coxe a ±20 e ±35, una zampa alla volta: libere.
- Zampe vicine AS–MS, MS–PS, AD–MD e MD–PD libere a 31°; si registra il contatto (in pianta 31,5°: 1,88 mm a 31°, 5,78 a 30°). Coppie AS–AD e PS–PD libere a 34° (in pianta contatto a 34,9°). Controllo: a 40° tocca.
- Carapace contro le zampe: ogni zampa con imbardata −35/0/+35 e (α, γ) = (85, 90), (85, 29), (60, 90). Nessuna interferenza; distanza minima di almeno 3,4 mm (in pianta 3,40 nella valle tra PS e MS, 4,32 tra AS e MS). Controllo: α 100 deve urtare.
- Testa: zampe anteriori a −35° con α −49/0/85 libere dal viso (circa 14 mm); lente a 0,9 mm dalla bugna dell'occhio.
- Ciclo a tripode 100/45 e 130/25 (4 fasi), 80/60 e 70/70 (16 fasi), giro a 100/45 e 70/70: nessun urto, con le cover nei gruppi SEGUONO_FEMORE e SEGUONO_TIBIA.
- Sfilamento del gruppo del carapace (con cicalino e pulsante) a +5, +10, +20, +40 mm: nessuna interferenza. Controllo: −2 mm deve urtare l'orlo delle baie.
- Campo della camera: tronco di piramide provvisorio da 54,2° e 46,1° dal bordo della lente, interferenza 0 con visiera, fascia e carapace (margine calcolato 0,80 mm). Controllo: +6° deve toccare.
- Sentinella dei volumi dopo ogni blocco; timeline senza avvisi né lavorazioni orfane; nessuna posa pendente; schizzi tutti vincolati.
- Massa: circa +74 g; statica_tripode.py con 2810 g: femore 49 %, ginocchio 45 % (≤ 50 %).

## Rischi aperti

- Smusso API (chamferFeatures) su un contorno di 30 lati con valli concave, seguito dallo svuotamento: non è mai stato usato negli script. Si prova in B0 su un documento di prova. Riserva: smusso da 4 mm, oppure smusso per tagli blocco_obl lato per lato.
- Zampe vicine: 31,5° è un conto in pianta. Il contatto è fra la lama A, a filo delle teste, e la lama B della vicina. A 31° restano 1,88 mm; al limite del firmware (30 + 30) 5,78. Va confermato in Fusion con Ingombro_Teste_A. Se a 31° tocca, la lama B passa a 1,0 mm.
- Margine del carapace dal femore ad α 85 e imbardata ±35: 3,4 mm, contro i 4,6 di Kabuto, perché le valli sono a y 56. Le anse dei cavi ad α alto vanno guardate sul provino.
- Fascetta del femore spostata nel blocco: è una modifica di D-058. La lunghezza totale dei cavi non cambia, ma si spostano le anse (più cavo fra ponte e femore ad α −49). Va provata con i cavi veri, compresa l'altezza dell'anello ad α 85 (circa 2,5 mm sopra il ponte).
- Ritenute a pressione: tubi della lama A sulle teste M3 (Ø5,4…5,7), spine della lama B (Ø2,9…3,1), tappi a rombo e labbro della ginocchiera, nervature di sportellino e collare. Dipendono dalla stampa e vanno tarate sul provino. In una caduta una cover può saltare.
- Stampa del carapace: 224,6 × 151,9 su un piatto da 256, con la zona di spurgo da confermare (D-050). Circa 180 cambi di testina, cioè da 30 a 60 minuti in più. Rischio di imbarcamento del guscio di PETG: servono brim e piatto caldo.
- Colori dei filamenti da approvare: E2 bianco, un PETG nero non caricato, E3 TPU arancio. Sono le uniche novità d'acquisto; viteria e inserti restano invariati. Senza l'arancio si possono fare i piedini neri.
- Massa circa 2805 g, 55 g sopra la massa di progetto. La statica resta sotto il 50 % (femore 49 %), con meno margine.
- Occhio: la bocca esterna intacca lo smusso del viso di 0,44 mm (sopra il campo, accettato). I conti assumono 120° in diagonale su 4:3 e la lente alla quota del modello: vanno confermati sulle prime immagini (ginocchia anteriori al bordo, D-057).
- Cicalino e pulsante: posizione del display, pin sul lato lungo, lunghezza del pulsante sotto il pannello (20 mm, con 9,7 liberi sopra lo zoccolo XBee). Si misurano sui pezzi comprati. Il pulsante va su un Dupont a 2 vie (C4).
- Dall'alto restano a vista le teste delle culle, con le estremità dei servo e le uscite dei cavi. È una scelta coerente con la regola dei giunti scuri, ma è il limite estetico rimasto.
- La lama A ha una fuga d'ombra di 1,8 mm, la B no: la sagoma è uguale, il dettaglio no. La visiera nera mostra lo spessore da 1,6 sui fianchi rastremati (si legge come piastra inserita).
- Nota fuori tema: la richiesta inoltrata con il workflow («aggiungi un readme leggero che riporti ai docs») è già soddisfatta. /Users/paul/hexapod-v2/README.md (commit 740099d) rimanda con una tabella a tutti i documenti. In questo lavoro non ho modificato la repo e in Fusion ho fatto solo una lettura dei parametri.

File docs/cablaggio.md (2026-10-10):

# Cablaggio

Tutti i cavi del robot nella versione 2.1.1 (D-067): da dove a dove, percorso (giunti attraversati, fascette, ganci), connettore, numero di fili e sezione.

- Quote in mm nella terna del robot: X avanti, Y a sinistra, Z in alto, origine al centro del corpo all'altezza degli assi dei femori.
- Le posizioni dei pezzi sono lette dal modello Fusion "Hexapod v2.1.0" (ingombri della libreria). Sezioni e connettori vengono dal BOM, segnali e pin da `piano-elettronica-software.md` (2.1–2.5) e da `predisposizioni.md`.
- Stato: **V** verificato, **S** stimato, **C** da confermare. Le voci X sono predisposizioni: il CAD c'è, l'acquisto va approvato (BOM, sezione X).

## 1. Dove stanno i pezzi

| Zona | Pezzi | Posizione (x; \|y\|; z) |
|---|---|---|
| Coda, porta di servizio | T-plug; portafusibile F1; cicalino BX100 sulla presa di bilanciamento; spie dei rail sotto il cicalino (X13); ToF posteriore sulla guancia sinistra (X19); altoparlante sulla guancia destra (X17) | T-plug −80…−64; F1 −83…−61; cicalino −87…−62, z 17…28; ToF y 12…25, altoparlante y −25…−22, tutti e due a x −100…−88 |
| Centro | SSC-32; interruttore 2813 in piedi fra SSC-32 e F1; due morsetti Wago, uno per lato | SSC-32 −51…22, \|y\| ≤ 28, z −7…25 (spine in alto, file degli header a \|y\| 23,5 da x 10,3 a −39,4); 2813 −58…−54; Wago −46…−16, \|y\| 28…36, z −30…−11 |
| Baie anteriori | regolatori D42V110F6 sulle slitte; INA260 sui supporti sopra (X7) | regolatori 14…57, \|y\| 33…45, z −29…2; INA260 14…37, \|y\| 29…40, z 9…31 |
| Davanti, vassoio | basetta con ESP32, D24V22F5, traslatore C1, buffer dei LED, partitore e abilitazione; sotto il vassoio IMU (X4) e ADC (X6); prese dei piedi sul tetto del tunnel; ToF frontale nella mensola della camera (X8) | basetta 22…78, z 6…8; IMU 36…59; ADC 39…70, y 1…18; prese 48…64, y 22…25; ToF 91…99 |
| Sotto il dorso (carapace) | scheda del carapace con la spina IDC (X2); amplificatore (X17); microfoni (X16); pulsante e camera dell'anello (X11); luci dei lobi (X12) | scheda 29…49, \|y\| ≤ 15, z 22…31; ampli 51…70; microfoni 83…96, \|y\| 3…19; pulsante x −40 |
| Tunnel | batteria | −85…79, z −39…−14 |

## 2. Schemi

**Potenza.** Sezioni dal BOM (B5, B6, B12, B14–B17).

```
Batteria 2S ─12 AWG─ T-plug ─12 AWG─ F1 30 A ─12 AWG─ Wago + ─┬─14 AWG─ D42V110F6 S ─16 AWG─ INA260 S ─16 AWG─ VS1 ─ 9 servo
   │                                  (Wago − : massa a stella) ├─14 AWG─ D42V110F6 D ─16 AWG─ INA260 D ─16 AWG─ VS2 ─ 9 servo
   │                                                            └─18/22 AWG─ F2 2 A ─ 2813 ─┬─ D24V22F5 5 V ─┬─ ESP32, pin 5V
   └─ bilanciamento JST-XH 3 poli ─ prolunga C7 ─ cicalino BX100                            │                ├─ PTC ─ LED: poli 1-2 del
                                                                                            │                │   connettore e ramo delle tibie
   VS1, VS2 ─ 1 kΩ ─ LED ambra ─ massa (spie, X13)                                          │                └─ amplificatore (poli 1-2)
   GPIO42 ─ 1N4148 ─ EN dei due D42V110F6 (47 kΩ a massa)                                   ├─ VL della SSC-32
   GPIO41 ─ OFF della 2813;  pulsante ─ A e B della 2813                                     ├─ partitore 100 k / 47 k ─ GPIO1
                                                                                            └─ D24V5F3 3,3 V sensori (X3, se serve)
```

Sulla SSC-32 le barre di rame da 1 mm (B16) corrono lungo le file VS e di massa di ogni lato.

**Segnali.**

```
ESP32-S3 ─ GPIO21 TX / GPIO14 RX ─ traslatore C1 ─ RX / TX della SSC-32 ─ 18 servo, canali in robot.yaml
         ─ GPIO47 SDA, GPIO3 SCL (I2C0, pull-up sulla basetta) ─┬─ IMU 0x6B e ADC 0x48 sotto il vassoio ─ 6 FSR, 2 NTC
                                                                ├─ INA260 0x44 e 0x45 nelle baie
                                                                ├─ ToF frontale 0x30 nella mensola
                                                                └─ connettore a 16 poli ─ scheda del carapace: Qwiic,
                                                                   TCA9534 0x20, ToF posteriore 0x31
         ─ GPIO48 ─ 10 kΩ a massa ─ SN74AHCT125N ── 330 Ω ─┬─ polo 4 ─ anello (4 pixel) ─ 6 lobi (2 pixel ciascuno)
                                                           └─ ramo delle tibie: 6 × 6 pixel in parallelo (ripetono i primi 6)
         ─ GPIO38 BCLK, 39 WS, 40 dati dei microfoni, 2 dati dell'ampli ─ poli 10-13 ─ 2 microfoni, ampli ─ altoparlante
         ─ camera OV3660: flat da 75 mm (SCCB su GPIO4 e 5, da sola)
```

**Zampa.** I fili della tibia salgono con il cavo del servo del ginocchio (D-058, D-067).

```
punta della tibia: FSR ─ tasca ─ gola 2 × 2 sullo stinco ──┐
striscia LED (6 pixel) ─ capo in alto a z −33 ─────────────┴─ gola del fermo sulla parete +X della culla,
   sotto tre ponticelli ─ testata della culla ─ si unisce al cavo del servo del ginocchio
   ─ ansa del ginocchio ─ fascetta nel blocco del femore ─ ansa dell'anca ─ fascetta del ponte (+ cavo del servo del femore)
   ─ sopra l'asse della coxa (ansa dell'imbardata) ─ sotto il coperchio a z 25 ─┬─ servo: canali della SSC-32
                                                                               ├─ FSR: prese dei piedi
                                                                               └─ LED: prese delle luci (lato −Y, D-069)
```

## 3. Cavi uno per uno

### 3.1 Potenza

| Cavo | Da → a | Percorso | Connettore | Fili e sezione | Stato |
|---|---|---|---|---|---|
| Batteria | pacco → T-plug | codino della batteria, dal tunnel alla coda | T-plug (la batteria ha la femmina) | 2 × 12 AWG | C sesso del T-plug |
| Principale | T-plug → F1 → Wago + ; T-plug → Wago − | in coda, poi lungo il fondo fino ai Wago sotto la SSC-32 | portafusibile in linea ATO con coperchio, fissato al corpo | 12 AWG siliconico, 0,5 m rosso + 0,5 m nero | S |
| Ingresso dei regolatori | Wago → D42V110F6 S e D | dai Wago (x −46…−16) alle baie anteriori (x 14…57), uno per lato | saldati | 14 AWG siliconico, 0,5 + 0,5 m | S |
| Rail servo | D42V110F6 → INA260 → file VS della SSC-32 | INA260 in serie sul positivo all'uscita di ogni regolatore; poi alla fila VS del suo lato | morsettiera dell'INA260 (C: deve reggere 13 A); barre B16 sulla SSC-32 | 16 AWG siliconico, 0,6 + 0,6 m | S, C morsettiera |
| Ramo logica | Wago + → F2 → 2813 | in coda: F2 in linea fra i Wago e la 2813 | portafusibile MINI | codini 18 AWG del portafusibile, poi 22 AWG | S |
| 5 V e VL | 2813 → D24V22F5 (basetta) → ESP32; 2813 → VL della SSC-32; 2813 → partitore → GPIO1 | dalla 2813 (x −56) alla basetta lungo il fianco del tunnel | saldati; VL con un Dupont (C4) | 22 AWG, più colori (circa 2 m in tutto) | S |
| 5 V dei LED | D24V22F5 → PTC → poli 1-2 del connettore del carapace; → ramo delle tibie | sulla basetta | saldati | 22 AWG fino alla basetta | S |
| Abilitazione del rail | GPIO42 → 1N4148 → EN dei due regolatori, 47 kΩ a massa | dalla basetta alle due baie | saldati | 22 AWG | S, valori da provare al banco |
| Spegnimento | GPIO41 → OFF della 2813 | dalla basetta alla 2813 | saldato; 100 kΩ a massa se scatta da sola (C) | 22 AWG | S |
| Pulsante | pulsante (x −40) → scheda del carapace → poli 15-16 → basetta → A e B della 2813 | sotto il dorso, poi nel cavo piatto | contatti a saldare sul pulsante; spina IDC | 2 fili | S |
| Spie dei rail (X13) | file VS1 e VS2 della SSC-32 → 1 kΩ → LED ambra → massa | dalla SSC-32 alla linguetta in coda sotto il cicalino | saldati | 2 + 2 fili, 22 AWG | S |
| Bilanciamento | presa JST-XH del pacco → prolunga C7 → cicalino BX100 | dal tunnel alla coda | JST-XH 3 poli | 3 fili | S; si stacca a fine uso |

### 3.2 Servo

Ogni servo ha il suo cavo a 3 fili (massa, +6 V, segnale), lungo 32 cm dichiarati: 30 utili tolta la spina. I percorsi sono quelli di `calc/cavi_servo.py`, con le anse di imbardata (10), anca (17) e ginocchio (20) e il 15 % in più per curve e fascette. Le spine vanno sui canali in alto della SSC-32; i canali sono in `robot.yaml` (C, proposta: lato sinistro 0–15, destro 16–31).

| Zampa | Canali coxa / femore / ginocchio | Percorso coxa | Percorso femore | Percorso ginocchio, margine | Prolunga |
|---|---|---|---|---|---|
| AS | 0 / 1 / 2 | 129 | 180 | 295, +5 mm (2 %) | sì, sul ginocchio |
| MS | 6 / 7 / 8 | 70 | 117 | 231, +69 mm (23 %) | no |
| PS | 13 / 14 / 15 | 112 | 158 | 267, +33 mm (11 %) | sì, sul ginocchio |
| AD | 16 / 17 / 18 | 129 | 181 | 295, +5 mm (2 %) | sì, sul ginocchio |
| MD | 22 / 23 / 24 | 70 | 117 | 231, +69 mm (23 %) | no |
| PD | 29 / 30 / 31 | 112 | 158 | 267, +33 mm (11 %) | sì, sul ginocchio |

- **Coxa**: il cavo sale dalla culla nella baia e va sotto il coperchio fino al canale. Non attraversa giunti.
- **Femore**: esce dall'alto della culla della coxa, sull'asse dell'anca. Passa sul braccio del ponte (fascetta da 2,5 mm nelle feritoie a X 28, \|Y\| 5,5, D-058) e sopra l'asse della coxa, dove l'imbardata cambia meno la lunghezza. Entra sotto il coperchio a z 25. Attraversa un giunto, l'imbardata.
- **Ginocchio**: esce dalla finestra del cavo nella testata della culla della tibia, sull'asse del ginocchio. Fa l'ansa del ginocchio, 22–40 mm al variare di γ, e passa nella fascetta dentro il blocco del femore (feritoie a X 79,5, tunnel a Z 10, D-060). Segue l'ansa dell'anca, 11–56 mm al variare di α, poi ponte, imbardata e canale come il femore. Attraversa tre giunti.
- **Prolunghe** (BOM C5): 4 JR maschio-femmina da 15 cm, 22 AWG, sui ginocchi delle zampe d'angolo. Le giunzioni si chiudono con il termorestringente (C6).
- I pettini per le anse dei cavi nelle baie posteriori sono in backlog: pezzi separati, da disegnare con le lunghezze misurate (`CLAUDE.md`, Backlog).

### 3.3 Zampa: sensore di forza e luci della tibia

| Cavo | Da → a | Percorso | Connettore | Fili e sezione | Stato |
|---|---|---|---|---|---|
| Sensore di forza (X5) | FSR sotto la punta dello stinco → prese dei piedi → partitore (10 kΩ 1 % al 3,3 V, 100 nF a massa) → ADS7830, canali 0–5 | coda dell'FSR piegata sul raccordo della punta, saldature nella tasca 6 × 9. Poi gola 2 × 2 sullo stinco fino al fondo della culla, gola del fermo sulla parete +X della culla sotto tre ponticelli, testata. Infine con il cavo del servo del ginocchio (3.2) fino alla fila delle prese | spina JR femmina (dalle prolunghe C5 avanzate, 2 poli su 3: segnale e massa) sulle prese dei piedi (x 48…64, y 22…25) | doppino 28 AWG siliconico, circa 0,4–0,5 m | S lunghezza; C canali: proposta nell'ordine di `robot.yaml` (AS, MS, PS, AD, MD, PD = 0…5) |
| Luci della tibia (X31) | capo alto della striscia (z −33) → prese delle luci (x 48…64, y −25…−22) → 5 V dopo il PTC, massa, dato dal buffer | dal capo della striscia alla gola del fermo, poi come l'FSR | spina JR a 3 poli: massa, +5 V, dato, come un servo | 3 × 30 AWG siliconico | prese nel CAD dalla 2.1.2 (D-069) |

- **Fili che attraversano i giunti**, per zampa: 8 al ginocchio e all'anca (servo del ginocchio, 2 dell'FSR, 3 delle luci). All'imbardata sono 11, con i 3 del servo del femore.
- **Gola del fermo** (D-067): larga 4 e profonda 0,8 sulla parete +X della culla, da z −33 a +12,45, a Y 4,4…8,4. Sta fuori dalle finestre a rombo e dai tappi del guscio. I tre ponticelli a z −28, −10 e +6 lasciano 1,1 mm sotto di sé. Si infilano i fili prima di saldarli all'altro capo.
- **Lungo la zampa passano solo massa e segnale dell'FSR, mai il 3,3 V** (`piano-elettronica-software.md` 2.2). Il 5 V delle luci ha la sua massa.

### 3.4 Bus dei sensori (X1) e ToF frontale

Bus I2C0: GPIO47 SDA, GPIO3 SCL, 3,3 V, 400 kHz. Ogni ramo ha 4 fili: massa, 3,3 V, SDA, SCL. Si usano cavetti Qwiic (JST SH 4 poli) dove la scheda ha la presa, altrimenti fili saldati.

| Ramo | Da → a | Percorso | Stato |
|---|---|---|---|
| Vano sotto il vassoio | basetta → IMU (0x6B) e ADS7830 (0x48) | dall'asola del vassoio | S |
| Baie anteriori | basetta → INA260 sinistro (0x44) e destro (0x45) | passaggio fra SSC-32 e vassoio, clip sul tetto | S |
| ToF frontale (X8) | basetta → VL53L7CX nella mensola della camera | lungo la torretta. Alimentato dal pin VDD a 3,3 V con VIN scollegato. Prende 0x30 a ogni accensione mentre il posteriore è tenuto spento | V alimentazione; S percorso |
| Carapace | basetta → poli 5–8 del connettore → scheda del carapace | cavo piatto | S |
| NTC dei regolatori (X14) | NTC sulla bobina di ogni regolatore → partitore (10 kΩ 1 %) → ADS7830, canali 6 e 7 | dalle baie al vano sotto il vassoio, fuori dal camino dei regolatori | S |

Il bus misura in tutto circa 1,1 m: 0,8 nel corpo e 0,3 nel carapace (S). Sta almeno 10 mm lontano dai cavi da 12–16 AWG e li incrocia a 90°.

### 3.5 Carapace

Tutto quello che sta sul carapace passa dalla **scheda del carapace** (X2): una striscia di millefori sotto il dorso, a x 29…49. La collega alla basetta un **cavo piatto a 16 vie**, lungo circa 15 cm, saldato sulla basetta e con la spina IDC sulla scheda; la spina si sfila dall'ottagono.

Piedinatura della testata 2 × 8, la stessa di `predisposizioni.md` 2.3:

| Polo | Segnale | Polo | Segnale |
|---|---|---|---|
| 1 | +5 V (LED e audio) | 2 | +5 V (LED e audio) |
| 3 | massa | 4 | dato dei LED a 5 V (dopo il buffer) |
| 5 | massa | 6 | SCL |
| 7 | +3,3 V sensori | 8 | SDA |
| 9 | massa | 10 | BCLK I2S |
| 11 | WS I2S | 12 | dati dei microfoni |
| 13 | dati verso l'amplificatore | 14 | riserva (XSHUT del ToF del mento, X25) |
| 15 | pulsante A (2813) | 16 | pulsante B (2813) |

| Cavo | Da → a | Percorso | Connettore | Fili | Stato |
|---|---|---|---|---|---|
| Catena LED (X9, X11, X12) | scheda → anello del pulsante → lobi PS, MS, AS, AD, MD, PD | dalla scheda lungo il lato sinistro dell'ottagono fino alla camera dell'anello. Entra dalla tacca verso la coda ed esce dalla stessa tacca. Poi lungo i fianchi nei ganci sotto il dorso (x −40, 0, 40, \|y\| 41,8–47,2), con il passaggio da sinistra a destra davanti | saldati sulle piazzole della striscia | 3 × 30 AWG (5 V, dato, massa) | S percorso; 16 pixel in tutto (D-068) |
| Dentro la camera dell'anello | due pezzi da due pixel (16,7 mm a 120 LED/m, D-068) nelle sedi del fondo, a Y ±(6,5…11,9) | entra al capo DIN del pezzo +Y, dalla parte della coda. Dal capo DOUT un ponticello di 3 fili gira attorno al corpo del pulsante sul lato della testa e va al capo DIN del pezzo −Y. Dal capo DOUT del pezzo −Y esce verso la tacca | saldati | 3 + 3 + 3 fili da 30 AWG | V spazio nel CAD (camera Ø32 × 6, D-067) |
| Pulsante | pulsante → scheda → poli 15-16 | sotto il dorso, circa 9 cm | saldati | 2 fili | S |
| Microfoni (X16) | due schede (x 83…96, \|y\| 3…19) → scheda | sotto il dorso, circa 5 cm | saldati | 5 per scheda: 3,3 V, massa, BCLK, WS, dati. I dati dei due microfoni sono uniti sul polo 12; SEL a massa su uno e a 3,3 V sull'altro | S |
| Amplificatore (X17) | scheda → ampli (x 51…70) | sotto il dorso | saldati | 5: 5 V, massa, BCLK, WS, dati | S |
| Altoparlante | ampli → altoparlante sulla guancia destra di coda | sotto il dorso, dalla testa alla coda, circa 17 cm | saldati | 2 | S |
| ToF posteriore (X19) | scheda → VL53L1X sulla guancia sinistra di coda | sotto il dorso, circa 15 cm | saldati | 5: 3,3 V, massa, SDA, SCL, XSHUT (dal TCA9534) | S |
| Espansione | presa Qwiic sulla scheda | si raggiunge dall'ottagono | JST SH 4 poli | 4 | V standard Qwiic |

### 3.6 Comandi dei servo e camera

| Cavo | Da → a | Connettore | Fili | Stato |
|---|---|---|---|---|
| Seriale della SSC-32 | ESP32 GPIO21 TX e GPIO14 RX → traslatore C1 → SSC-32 | Dupont femmina (C4) | 4: TX, RX, massa, VL | V pin (D-012) |
| Camera | OV3660 → ESP32 | flat da 75 mm | — | V |
| USB | ESP32 → Mac al banco, poi l'eventuale computer di bordo | USB-C della scheda, sotto l'ottagono (con lo zaino il cavo esce dalla tacca del suo sportellino) | — | — |

## 4. Smontaggio

- **Carapace**: si toglie lo sportellino, si sfila la spina IDC dall'ottagono, si svitano le 4 viti, si stacca il cicalino dalla presa di bilanciamento e si solleva. Anello, fondo, lobi, microfoni, ampli, altoparlante e ToF posteriore restano sul carapace con i loro fili.
- **T-plug** (sezionamento d'emergenza): sta 7 mm dentro la porta di coda, appoggiato al portafusibile, con 3,3 mm sotto il cicalino. Si prende con la punta delle dita sul retro e sui fianchi: 7 mm d'aria verso l'altoparlante, 10,4 mm verso la guancia sinistra. Il ToF posteriore copre solo l'angolo in alto a sinistra (3 × 3 mm) visto da dietro e sta 8 mm più indietro (verifica della 2.1.2). Si prova a mano sul primo carapace; se è scomodo, una linguetta di nastro sulla metà lato batteria.
- **Zampa**: si staccano dalla SSC-32 le tre spine dei servo, poi la spina dell'FSR dalle prese dei piedi e quella delle luci dalle sue prese. Tutti questi fili restano sulla zampa.

## 5. Aperti

1. **Prese delle luci delle tibie**: fatte nella 2.1.2 (D-069). Seconda fila di sei spine JR a 3 poli (massa, +5 V, dato, l'ordine dei servo) speculare a quella dei piedi, sul tetto del tunnel a x 48…64, y −25…−22, nessuna interferenza.
2. **Il ramo delle tibie ripete i primi sei pixel della catena**. Oggi sono i quattro dell'anello e i due del primo lobo, quindi le tibie avrebbero gli stessi colori. Per tenerle indipendenti servono sei pixel nascosti in testa alla catena, per esempio 5 cm di striscia sulla basetta. Da decidere con X31.
3. **Tetto di corrente**: i 600 mA del firmware devono contare ogni pixel delle tibie sei volte (36 pixel reali per 6 indirizzi).
4. **Lunghezze dei fili** (S): si misurano sulla prima zampa montata, prima di tagliare gli altri cinque.
5. **Pettini delle anse** nelle baie posteriori: in backlog, come pezzi separati sulla parete del tunnel, da disegnare dopo il montaggio di una zampa con le lunghezze misurate (`CLAUDE.md`, Backlog).
6. **Wago**: il positivo sta sul lato sinistro (+Y), il negativo, massa a stella di tutti i rami, sul destro (−Y), come nell'assieme (`assieme.py` → `Wago_piu`, `Wago_meno`).

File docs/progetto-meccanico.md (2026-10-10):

# Progetto meccanico — versione MG996R

Stato al 9 ottobre 2026: **zampa v0.1 modellata, rivista da quattro revisori e corretta** (D-047, D-048, D-049), verificata in Fusion con i giunti veri. Corpo v0 e assieme con sei zampe e giunti di coxa modellati e verificati (D-050). **Passata estetica applicata** (D-060…D-063): carapace al posto del coperchio, cover delle zampe, tibia simmetrica; vedi "Passata estetica" più sotto.

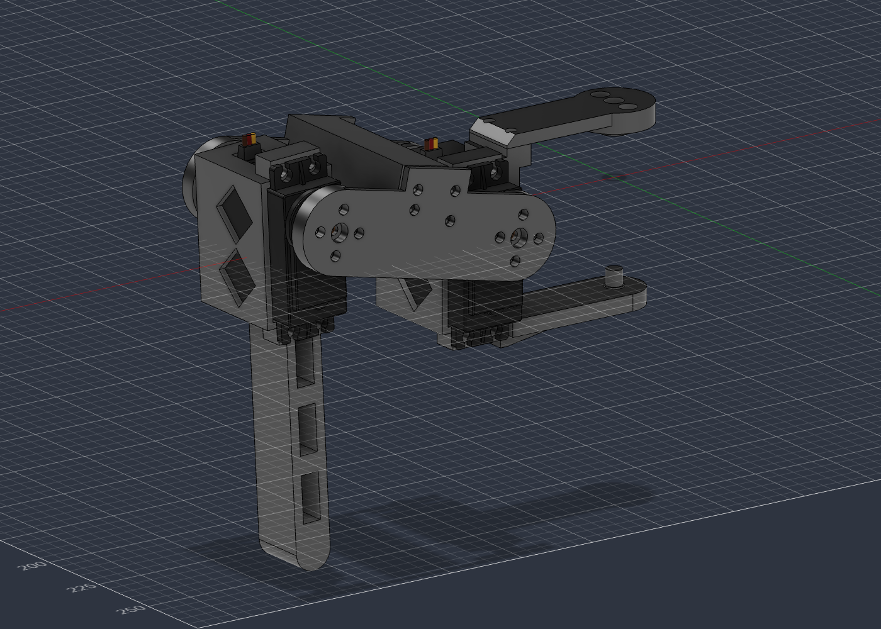
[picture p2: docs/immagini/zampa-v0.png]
Zampa v0, femore a +12°, ginocchio a 75°


## Zampa

### Come è nata

Tre architetture indipendenti, ciascuna con una priorità diversa, giudicate da tre revisori. Dettagli, numeri e calcoli dei revisori in `ricerca/zampa-architetture.json`.

| Proposta | Idea | Massa stimata | Esito |
|---|---|---|---|
| scalata | prima versione portata in scala: servo di coxa nel corpo, coxa a C, femore in due piastre, servo del ginocchio nella tibia; coda del servo del femore girata in basso | 84 g (90–98 secondo il revisore geometrico) | **base**: 7,5 / 6 / 7,5 |
| compatta | coxa corta (34 mm) con il servo di coxa girato, femore 60 | 64 g | 5,5 / 4,5 / 6,5: coxa senza registro assiale, femore chiuso da 2 viti |
| robusta | femore a cassone con dentro i servo di anca e ginocchio | 117 g | 6 / 7 / 4,5: femore e ginocchio oltre il 50 % per architettura |

### Architettura

Terna della zampa (componente `Zampa`): origine sull'asse della coxa, all'altezza dell'asse del femore; X verso l'esterno, Y lungo l'asse del femore verso la piastra delle squadrette, Z in alto. Posa di riferimento: femore orizzontale (α = 0), tibia verticale (γ = 90°). La punta del piede sta sul piano della zampa (Y 0, D-065).

| Parte | Cosa fa | Come si stampa |
|---|---|---|
| `Coxa` | culla del servo del femore (coda in basso), anima verso il corpo che gira fuori dalla gondola, braccio inferiore sotto la gondola con il perno della coxa | orlo della culla (+Y) sul piano, senza supporti |
| `Coxa_Ponte` | braccio superiore della C: porta la squadretta del servo di coxa, avvitato all'anima con 2 M3 e centrato da una linguetta | faccia superiore sul piano |
| `Femore_B` | piastra dei perni (perni di anca e ginocchio forzati) con il blocco cavo che chiude la sezione | faccia esterna sul piano, blocco in piedi |
| `Femore_A` | piastra delle squadrette: porta tutta la coppia tra anca e ginocchio; 8 M3 nelle squadrette, 4 M3 nel blocco | faccia esterna sul piano |
| `Tibia` | culla del servo del ginocchio (coda verso il piede) e stinco cavo | orlo della culla sul piano |
| `Piedino` | cappuccio in TPU | punta in alto |

Quote principali (dal modello di verifica `calc/zampa_escursioni.py`, da confermare nel CAD):
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

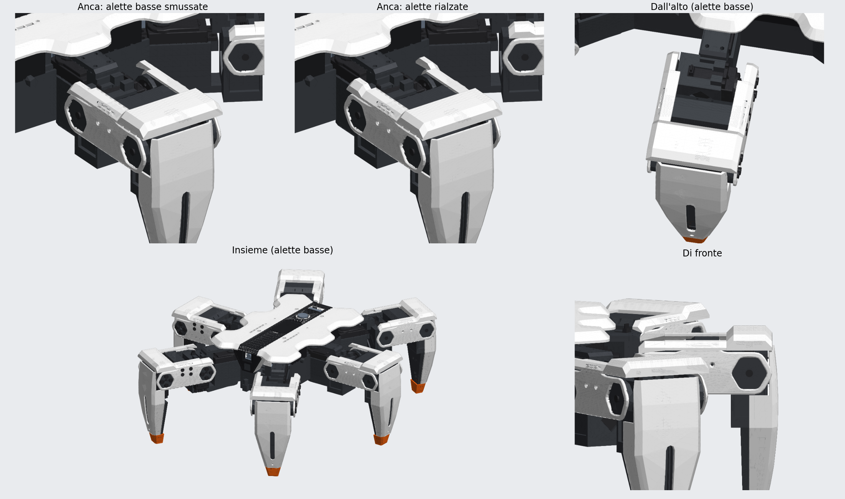
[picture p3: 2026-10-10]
docs/ricerca/estetica/8-placca-femore/confronto_rifinita.png

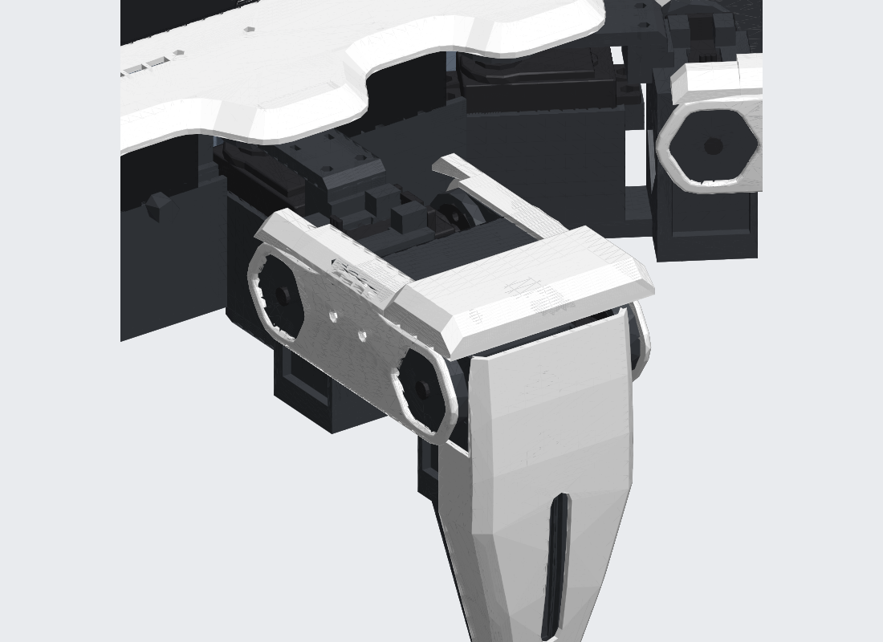
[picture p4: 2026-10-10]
docs/ricerca/estetica/8-placca-femore/1r-anca-bassa_zampa_vista_28_55.png

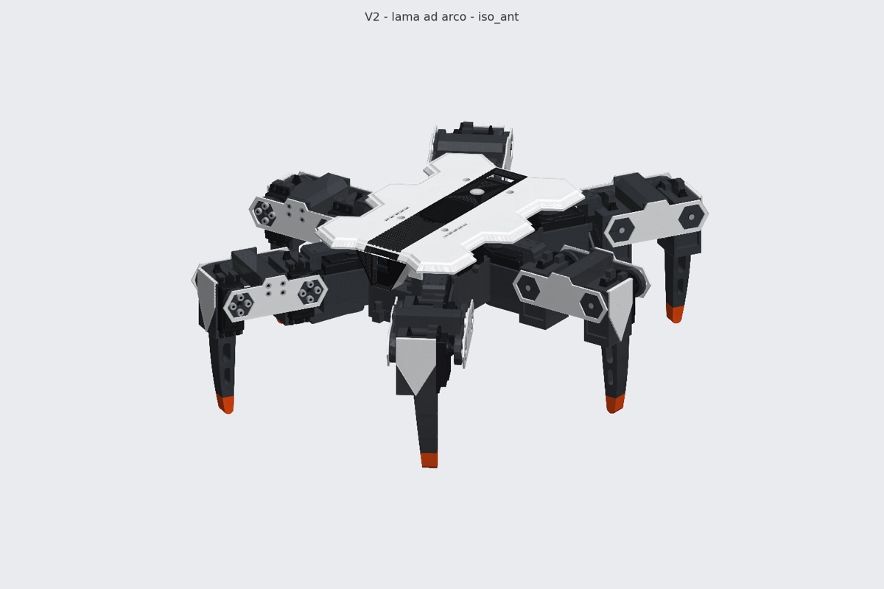
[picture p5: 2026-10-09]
docs/ricerca/estetica/6-tibia/tibia_v2_iso_ant.jpg

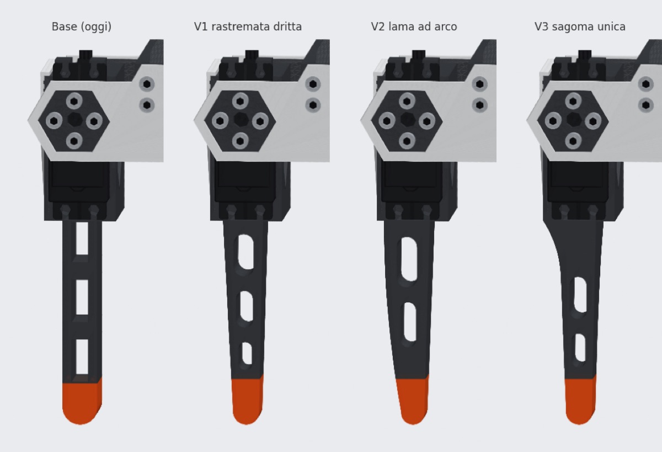
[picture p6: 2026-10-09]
docs/ricerca/estetica/6-tibia/confronto_profilo.jpg

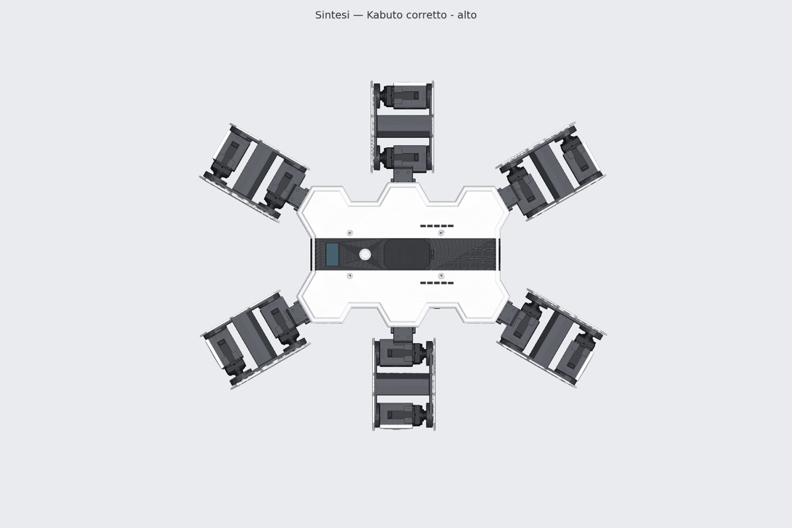
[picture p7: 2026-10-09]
docs/ricerca/estetica/4-sintesi/sintesi_alto.jpg

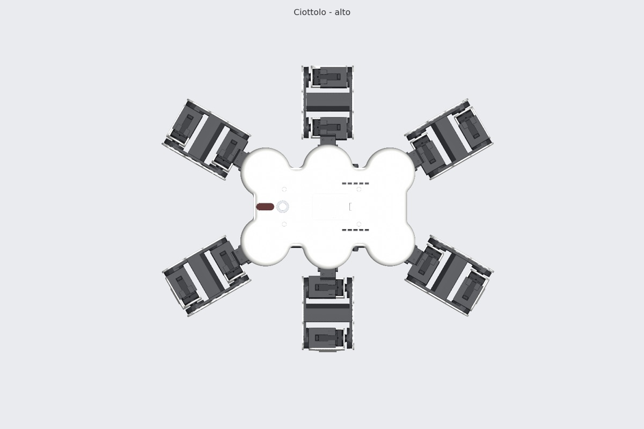
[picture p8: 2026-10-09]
docs/ricerca/estetica/2-ciottolo-levigato/levigato_alto.jpg

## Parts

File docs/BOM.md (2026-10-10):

# BOM — Hexapod v2 (MG996R)

Versione 2.1 (10 ottobre 2026): prezzi e link d'acquisto letti il 10 ottobre 2026, carrelli per negozio e costo totale. Versione 2.0 (8 ottobre 2026) **approvata dall'utente** l'8 ottobre 2026. Le domande in fondo restano aperte: non bloccano il CAD. Nasce dallo studio in `studio-componenti.md`; il perché delle scelte è lì e in `decisioni.md` (D-043, D-045).
La viteria è provvisoria: misure, lunghezze e quantità esatte si ricavano dal modello nella fase 5.

Foto: immagini dei prodotti scelti, collegate dai siti dei negozi e dei produttori (non copiate nella repo: se un negozio cambia pagina, la foto può sparire).
Legenda **dato**: V = verificato su fonte primaria; S = stimato o da fonte secondaria; C = da confermare sul pezzo reale.
Legenda **stato**: P = già in tuo possesso; A = da comprare; ? = dimmi tu; — = non comprare per ora.
Prezzi in euro **IVA inclusa**, letti il 10 ottobre 2026 sulle pagine dei negozi (V) oppure stimati (S: conversione da PLN, SEK, USD o pagina non leggibile). I prezzi di Amazon.it e AliExpress sono letti nelle pagine aperte in Chrome sul Mac dell'utente. Si ricontrollano all'ordine. Criterio di scelta (D-068): il costo consegnato in Italia, spedizioni comprese, con pochi negozi; AliExpress solo per la minuteria, con l'alternativa europea. Il carrello per negozio e il totale sono nella sezione "Carrelli e costo totale".

## Schema di alimentazione

```
Batteria 2S ── T-plug ── F1 (30 A) ── derivazione + ──┬── regolatore 6 V sinistro ── file VS1 e massa della SSC-32, dal retro (9 servo)
                                                      ├── regolatore 6 V destro   ── file VS2 e massa della SSC-32, dal retro (9 servo)
                                                      └── F2 (2 A) ── interruttore ──┬── regolatore 5 V ── ESP32
                                                                                     ├── VL della SSC-32 (logica)
                                                                                     └── partitore ── GPIO1
GPIO42 ── diodo ── pin di abilitazione dei due regolatori 6 V (tirati a massa: rail spento di default)
Presa di bilanciamento ── cicalino di sottotensione
```

- I due regolatori servo sono sempre collegati alla batteria ma **spenti di default**: li accende l'ESP32 quando la SSC-32 sta già mandando impulsi. Nel percorso dei servo non c'è nessun interruttore.
- La potenza dei servo entra nelle file degli header **dal retro della SSC-32**, con un filo stagnato saldato lungo i pin: i morsetti e le piste della scheda non la portano. Ponticelli "VS1 VS2" e "VS VL" tolti.
- L'interruttore sta sul ramo logica (meno di 1 A). **A fine uso si staccano T-plug e presa di bilanciamento**: il T-plug è anche il sezionamento d'emergenza dei servo.
- I negativi si uniscono in un solo punto (massa a stella) accanto ai regolatori.

## A. Già in possesso

| # | Foto | Componente | Q.tà | Modello / codice | Specifiche chiave | Dato | Stato |
|---|---|---|---|---|---|---|---|
| A1 | A1 | Servo | 18 | AZDelivery MG996R (confezioni da 5) | 55 g; 9,4 kgf·cm a 4,8 V, 11 a 6 V; 4,8–7,2 V; 2,5 A di stallo a 6 V; 40,7 × 19,7 × 42,9 mm; due cuscinetti; squadrette di plastica e viteria incluse | V (datasheet AZDelivery) | P |
| A2 | A2 | Scheda di controllo | 1 | UICPAL "ESP32-S3-CAM N16R8 RE1.3" | ESP32-S3 N16R8; 62,6 × 28,3 mm (67,5 con l'antenna); 2 USB-C; nessun foro di fissaggio | S, C | P (da confermare) |
| A3 | A3 | Camera | 1 | UICPAL "OV3660-75MM", lente 120° "GOOD" | flat da 75 mm; testa 8,5 × 8,5 mm, alta circa 6 mm | S, C | P (da confermare) |
| A4 | A4 | Servo controller | 1 | clone "SSC32-V2.5" (AliExpress 1005001888185034) | 32 canali; PCB 72 × 55 mm, fori a 65,5 × 48,5 mm; header a foro passante; VL 6–12 V | S (disegno del venditore) | P |
| A5 | A5 | Batteria | 1 | OVONIC 2S 5200 mAh 50C hardcase, T-plug | 137–139 × 46–47 × 24–25 mm; 245–259 g; 260 A continui; cavi 12 AWG; bilanciamento JST-XH. Autonomia stimata 22–27 minuti in marcia classica | V (pagine del produttore) | P |

## B. Alimentazione

| # | Foto | Componente | Q.tà | Modello / codice | Specifiche chiave | Acquisto (10 ottobre 2026) | Dato | Stato |
|---|---|---|---|---|---|---|---|---|
| B1 | B1 | Regolatore del rail servo, 6,0 V | 2 (uno per lato) | **Pololu D42V110F6 (#5673)** | ingresso fino a 60 V; 11 A tipici dichiarati a 42 V, di più con ingresso basso (circa 13–14 A con la 2S: S); limita la corrente con gradualità; pin di abilitazione e power-good; protezione da inversione; 43,2 × 31,8 × 9 mm; 4 fori M2. Se al banco non basta, al suo posto va il D24V150F6 (#2882), stesso ingombro | Kamami: [D42V110F6](https://kamami.pl/step-down/1201579-6v-11a-step-down-voltage-regulator-d42v110f6-5902186330856.html), 2 × 52,38 € (V, gli ultimi 2 a magazzino). pololu.com 59,95 US$ più IVA e spedizione | V | A |
| B2 | B2 | Regolatore 5 V per l'ESP32 | 1 | Pololu D24V22F5 (#2858) | 5 V, 2,5 A; 17,8 × 17,8 mm; 2 fori M2 | Kamami: [D24V22F5](https://kamami.pl/en/step-down/561020-pololu-5v-25a-step-down-voltage-regulator-d24v22f5-pololu-2858-5906623437580.html), 17,84 € (V) | V | A |
| B3 | B3 | Interruttore generale (ramo logica) | 1 | Pololu Big Pushbutton Power Switch HP (#2813) | a pulsante; pin OFF per lo spegnimento da firmware; meno di 0,2 µA da spento; 20,3 × 25,4 mm | Kamami: [Pololu 2813](https://kamami.pl/en/digital-switches/561034-pololu-2813-big-pushbutton-power-switch-with-reverse-voltage-protection-hp-5906623477883.html), 7,87 € (V) | V | A |
| B3b | B3b | Pulsante d'accensione | 1 + 1 | pulsante da pannello Ø12 mm, momentaneo, normalmente aperto, a vite con dado, contatti a saldare | sul coperchio, collegato ai pin A e B della 2813 (in parallelo al suo pulsantino, come indica la pagina Pololu); corpo sotto il pannello circa 20 mm, da confermare sul modello scelto | Kamami: [pulsante 12 mm con dado](https://kamami.pl/przyciski/582435-momentary-push-button-okragly-przycisk-chwilowy-12mm-zolty-5906623460052.html), 2 × 0,58 € (V; giallo, alto 21 mm, NO o NC non dichiarato: C) | S | A (approvato il 9 ottobre 2026) |
| B4 | B4 | Fusibile principale F1 | assortimento 15 / 20 / 25 / 30 A | lama ATO/ATC, 32 V | 30 A in uso; 15 A per le prime accensioni | Kamami: [set Yato YT-83148](https://kamami.pl/bezpieczniki/1204000-zestaw-bezpiecznikow-ministandard-301szt-yt-83148-5906083091049.html), 301 fusibili ATO e MINI da 2 a 40 A, 7,73 € (V); copre anche i MINI da 2 A di B6 e i 3 e 5 A del banco | S | A |
| B5 | B5 | Portafusibile principale | 1 | in linea per lame ATO/ATC, cavi 12 AWG, con coperchio | da fissare al corpo, non appeso ai cavi | Amazon.it: [Gebildet, 4 portafusibili ATO 12 AWG con tappo](https://www.amazon.it/dp/B0BCW47SDY), 8,99 € (V, letto in Chrome) | S | A |
| B6 | B6 | Fusibile del ramo logica F2 | 1 + 1 | portafusibile in linea MINI 18 AWG + fusibile MINI 2 A | il ramo logica usa cavo da 22 AWG: F1 da solo non lo proteggerebbe | Kamami: [portafusibile MINI con cavo 1 mm²](https://kamami.pl/zlacza-inne/1197193-gniazdo-bezpiecznika-10-mini-5900804107170.html), 0,92 € (V); fusibili da 2 A nel set di B4 | S | A |
| B7 | B7 | Condensatore sul rail servo | 2 + 2 | elettrolitico 2200 µF 16 V a bassa ESR, es. Panasonic EEUFR1C222 | Ø12,5 × 20 mm; saldato a una spina servo e inserito in un canale libero, uno per lato | Amazon.it: [2200 µF 16 V low ESR 13 × 21, 20 pz](https://www.amazon.it/dp/B0FH27HTJL), 15,00 € (V). Con le voci X: DigiKey [EEU-FR1C222](https://www.digikey.it/en/products/detail/panasonic-electronic-components/EEU-FR1C222/2433536), 4 × 1,79 € (**alto fino a 22 mm**, non 20) | S | A |
| B8 | B8 | Condensatore ceramico | 3 | 100 nF 50 V | due in parallelo a B7, uno sull'ingresso dell'ADC | Amazon.it: [BOJACK 100 nF 50 V](https://www.amazon.it/dp/B07Y7PHY91), 8,99 € (V). Con le voci X: DigiKey, 0,18 € l'uno | S | A |
| B9 | B9 | Allarme di sottotensione | 1 | cicalino LiPo 1–8S tipo "BX100" | sulla presa di bilanciamento; soglia regolabile; assorbe sempre: si stacca a fine uso | Kamami: [BX100](https://kamami.pl/wskazniki-rozladowania/582354-bx100-tester-napiecia-pakietow-lipo-1-8s-5906623459704.html), 3,50 € (V); posizione dei pin da guardare sul pezzo | S | A |
| B10 | B10 | Partitore per la misura di batteria | 1 + 1 | resistenze 100 kΩ e 47 kΩ, 1 % | 8,4 V → 2,69 V su GPIO1 | Kamami: [set resistenze 1 % da 820 pezzi](https://kamami.pl/rezystory-tht-14w/1199442-zestaw-rezystorow-cf-tht-14w-1-1-1-m-820-szt--5902186309630.html), 6,12 € (V): 100 k e 47 k; serve anche per B11 e per le voci X | V (campo ADC) | A |
| B11 | B11 | Accensione del rail servo | 1 + 1 | resistenza 47 kΩ (più una da 22 kΩ di riserva) e diodo 1N4148 | pin di abilitazione dei due B1 uniti e tirati a massa; GPIO42 → diodo → abilitazione. La soglia bassa non è pubblicata: valori da provare al banco | Kamami: [1N4148, 10 pz](https://kamami.pl/diody-schottky/1187768-dioda-impulsowa-1n4148-tht-500mw-75v-10-szt-5906623484720.html), 0,58 € (V); 47 k dal set di B10; il 22 k di riserva c'è solo al 5 % (0,01 €) | S, C | A |
| B12 | B12 | Connettore batteria lato robot | 1 conf. | T-plug maschio con codino **12 AWG** | la batteria ha la femmina (dalle immagini del produttore: da guardare sul pacco) | Amazon.it: [Deans T-plug con cavo 12 AWG, 3 coppie](https://www.amazon.it/dp/B07QM1WS2J), 10,99 € (V, 924 recensioni) | S, C | A |
| B13 | B13 | Derivazioni di potenza | 2 | morsetto a leva a 5 vie Wago 221-415 | fino a 4 mm², 32 A: uno per il positivo, uno per il negativo (massa a stella) | Kamami: [Wago 221-415](https://kamami.pl/szybkozlacza/1188363-wago-221-415-zlaczka-instalacyjna-5-przewodow-4mm-5902186324558.html), 2 × 0,81 € (V) | S | A |
| B14 | B14 | Cavo di potenza principale | 0,5 m rosso + 0,5 m nero | siliconico 12 AWG | T-plug → F1 → derivazioni | Amazon.it: [MMOBIEL siliconico 12 AWG rosso e nero](https://www.amazon.it/dp/B0CRVK6Q9C), 14,99 € (V) | S | A |
| B15 | B15 | Cavi verso i regolatori e la SSC-32 | 0,5 m + 0,5 m di 14 AWG; 0,6 m + 0,6 m di 16 AWG | siliconico | 14 AWG dalle derivazioni agli ingressi dei B1; 16 AWG dalle uscite dei B1 alle file della SSC-32 | Amazon.it: [TUOFENG 14 AWG 1,5 + 1,5 m](https://www.amazon.it/dp/B075M578PB) 9,99 € e [MMOBIEL 16 AWG](https://www.amazon.it/dp/B0CRVMJQJF) 11,99 € (V) | S | A |
| B16 | B16 | Barre sulle file degli header | 1 m | filo di rame stagnato rigido Ø1 mm (18 AWG) | saldato sul retro della SSC-32 lungo le file VS e di massa di ogni lato | Amazon.it: [QWORK filo di rame Ø1 mm, 10 m](https://www.amazon.it/dp/B0F6XSTY6Z), 8,34 € (V; rame nudo, si stagna) | — | A |
| B17 | B17 | Cavo logica | circa 2 m | siliconico 22 AWG, più colori | ramo logica, VL, 5 V, partitore, abilitazione | Amazon.it: [siliconico 22 AWG, 6 colori × 10 m](https://www.amazon.it/dp/B0F892PSQK), 15,99 € (V) | S | A |
| B18 | B18 | Distanziali | 4 | **M3 maschio-femmina da 5 mm** per il vassoio dell'ESP32 (D-051, approvato il 9 ottobre 2026; i regolatori stanno su slitte stampate e la SSC-32 su bugne del corpo) | | Amazon.it: [QUARKZMAN M3 × 5 + 5 maschio-femmina, 12 pz](https://www.amazon.it/dp/B0GGLL9HKK), 9,99 € (V) | — | A |
| B19 | B19 | Termorestringente, stagno, flussante | 1 assortimento | — | giunzioni saldate | Kamami: [guaina 4/2 mm 10 × 1 m](https://kamami.pl/rurki-termokurczliwe/569152-rurki-termokurczliwe-czarne-4020-10-szt-x-1-metr-5900804072157.html) 2,99 €, [stagno 0,7 mm 100 g](https://kamami.pl/cyna-olowiowa/549284-cyna-lc60-070mm-100g-5906623404964.html) 7,47 €, [flussante 50 ml](https://kamami.pl/topnik-w-plynie/547791-topnik-tk-83-50ml-oliwiarka-ag-5901764323600.html) 1,98 € (V) | — | A |

Nota su B1: un regolatore serve 9 servo. Corrente stimata per lato: 5–6 A medi nella marcia classica, 8–9 A in quella bassa, picchi di 12–15 A, contro circa 13 A disponibili; oltre, il regolatore limita la corrente e il rail cala, senza spegnersi. Lo stallo contemporaneo di 9 servo (22,5 A) lo impedisce il firmware.

## C. Controllo, segnali, cablaggio dei servo

| # | Foto | Componente | Q.tà | Modello / codice | Specifiche chiave | Acquisto (10 ottobre 2026) | Dato | Stato |
|---|---|---|---|---|---|---|---|---|
| C1 | C1 | Traslatore di livello 3,3 V ↔ 5 V | 1 | modulo a 4 canali con BSS138 (tipo Adafruit 757) | TX e RX tra ESP32 e SSC-32 | Kamami: [KAmod Level Shift x4](https://kamami.pl/konwertery-napiec/1195428-kamod-level-shift-x4-dwukierunkowy-4-kanalowy-konwerter-poziomow-logicznych-5906623499489.html), 2,51 € (V; il MOSFET non è dichiarato, C). Adafruit 757 vero: [DigiKey](https://www.digikey.it/en/products/detail/adafruit-industries-llc/757/4990756), 4,23 € | S | A |
| C2 | C2 | Basetta di supporto | 1 + 2 + 1 | millefori 50 × 70 mm; 2 strip femmina 1 × 20; 1 strip maschio 1 × 40 | zoccolo per l'ESP32 (che non ha fori) e supporto per B2, C1, B10, B11; si taglia a 56 × 35 (D-053) | Kamami: [millefori 50 × 70](https://kamami.pl/plytki-uniwersalne/1204291-kamod-proto-50x70-dwustronna-plytka-uniwersalna-50-x-70-mm-5902186339903.html) 1,82 € e [strip maschio 1 × 40](https://kamami.pl/zlacza-goldpin/1207864-goldpin-czarny-1x40-szpil-prosty-do-druku-raster-254mm-5906623439881.html) 0,43 € (V); strip femmina: Amazon.it [Ticfox 1 × 40, 5 pz](https://www.amazon.it/dp/B09JP7HT1W), 8,39 € (V) | C | A |
| C3 | C3 | Ingresso del 5 V nell'ESP32: alternativa | 1 + 1 | spinotto USB-C maschio a 90° a saldare + diodo Schottky 1N5817 | solo se la scheda non si accende dal pin 5V | spinotto: Amazon.it [USB-C maschio a 90° con 2 fili, 5 pz](https://www.amazon.it/dp/B0D2TN7M5B), 8,98 € (V). Diodo: Kamami [1N5819](https://kamami.pl/diody-schottky/1187767-dioda-schottkiego-1n5819-tht-40v-1a-10-szt-5906623484713.html), 0,46 € per 10 (V; il 1N5817 non c'è, il 1N5819 da 40 V lo sostituisce) | C | A |
| C4 | C4 | Cavetti verso la SSC-32 | 1 conf. | Dupont femmina 10–20 cm | TX, RX, massa, VL | Kamami: [Dupont F-F 10 cm, 40 pz](https://kamami.pl/przewody-f-f/584964-przewody-polaczeniowe-f-f-roznokolorowe-10-cm-40-szt-5906623461738.html), 1,13 € (V) | — | A |
| C5 | C5 | Prolunghe servo | 4 (confezione da 20) | JR maschio-femmina 15 cm, 22 AWG | dal CAD (`calc/cavi_servo.py`): i ginocchi delle zampe d'angolo hanno percorsi di 267–295 mm contro circa 300 utili (32 cm dichiarati), margine 2–11 %; gli altri 14 servo bastano con margine (23–77 %). Con 2,5 A una prolunga da 15 cm in 22 AWG perde circa 40 mV | Kamami: [prolunga JR 15 cm 22 AWG](https://kamami.pl/przewody-do-serw/586760-przedluzacz-do-serw-15cm-5906623462988.html), 4 × 1,34 € (V). Amazon.it B087289HFS, 20 pz circa 9 € (S) | S | A (approvato il 9 ottobre 2026) |
| C6 | — | Clip di blocco delle prolunghe | — | — | non servono: le 4 giunzioni si chiudono con il termorestringente (B19) | — | — | — |
| C7 | C7 | Prolunga di bilanciamento | 1 | JST-XH 3 poli, 10–20 cm | porta la presa di bilanciamento dove si raggiunge senza togliere il pacco | AliExpress: [JST-XH 2S 20 cm 22 AWG, 5 pz](https://it.aliexpress.com/item/1005004996032030.html), 2,32 € (V). Amazon.it [YIXISI 2S, 10 pz](https://www.amazon.it/dp/B08JV8QW3M), 8,99 € | S | ? (dopo il CAD) |
| C8 | — | Antenna esterna | 1 | 2,4 GHz con cavetto IPEX | solo se la portata a guscio montato non basta | Amazon.it | C | — |

## D. Giunti e meccanica

Ogni giunto: il servo è stretto in una culla e appoggia sulle alette; l'albero porta una squadretta metallica avvitata alla parte mobile; sul lato opposto, coassiale, un cuscinetto flangiato e un perno.

| # | Foto | Componente | Q.tà | Modello / codice | Specifiche chiave | Acquisto (10 ottobre 2026) | Dato | Stato |
|---|---|---|---|---|---|---|---|---|
| D1 | D1 | Cuscinetto del lato opposto all'albero | 18 + 6 | flangiato schermato **5 × 10 × 4** (NMB LF-1050ZZ, venduto come MF105ZZ) | flangia Ø11,6 × 0,8 nella versione NMB (nei generici da 11,2 a 11,7); carico statico 276 N, dinamico 714 N, contro poche decine di newton di lavoro. Ordinare "ZZ" | a tua cura. Riferimento: Amazon.it [METERXITY MF105ZZ 20 pz](https://www.amazon.it/dp/B0F4QWY4XZ) 19,90 € + [4 pz](https://www.amazon.it/dp/B0F4QWG4YM) 10,72 € (V) | V (NMB) | A |
| D2 | D2 | Perno del cuscinetto | 18 + 6 | spina cilindrica **Ø5 × 12**, tolleranza h8 se si trova (ISO 2338), altrimenti m6 (ISO 8734); lunghezza fissata dal CAD della zampa (D-047) | le m6 entrano forzate nel cuscinetto: provarle su un cuscinetto campione | a tua cura. Riferimento: Amazon.it [QUARKZMAN 5 × 12 inox 316L, 40 pz](https://www.amazon.it/dp/B0FGJKXFY3), 11,69 € (V; tolleranza non dichiarata) | S, C | A |
| D3 | D3 | Squadretta lato albero | 18 + 2 | disco in alluminio per servo a **25 denti** con fori M3, dichiarato compatibile MG996R | sostituisce la squadretta di plastica: niente gioco e niente deformazione con 2,6 kg. I 25 denti dell'MG996R sono il dato comune dei servo di questa taglia: prima di ordinarne 20, provarne una su un tuo servo | AliExpress: [disco 25T per MG995/MG996](https://it.aliexpress.com/item/1005002538112794.html), 0,42 € l'uno, 24 pz 10,08 € (V; diametro e fori non dichiarati: si provano 1–2 pezzi). Con le misure del CAD (Ø20, fori M3 filettati a 14 mm): Amazon.it [diymore 25T, 6 pz](https://www.amazon.it/dp/B07G5BTMJB), 10,99 € (V) | S, C | A |
| D4 | — | Inserti a caldo M3 | 94 | **dal kit dell'utente** (Temu, "brass insert nut + screw set" M2/M3, 800 pezzi): M3 × 5 × Ø4,2 e M3 × 6 × Ø4,2, 50 per misura (anche × 3 e × 4) | alette dei servo (72 tra lato coda e corpo), zampe, corpo, coperchi | già in possesso; i fori (`ins_m3_d`, oggi 4,2 per i CNC Kitchen Ø4,6) si tarano sul provino | S | in possesso |
| D5 | — | Inserti a caldo M2 | 28 | **dal kit dell'utente**: M2 × 3 × Ø3,2 (anche × 2, × 4, × 5), 50 per misura | regolatori, SSC-32, basetta, lame B dei femori (D-065) | già in possesso; foro `ins_m2_d` (oggi 3,4) da tarare sul provino | S | in possesso |
| D6 | D6 | Viti M3 | assortimento + 100 | testa cilindrica con esagono incassato (ISO 4762), inox A2, 6–25 mm; **in più 12 × M3 × 5** per le squadrette della coxa (D-049, approvate il 9 ottobre 2026) | alette dei servo, squadrette metalliche, zampe, corpo | Amazon.it: [kit inox M3 da 1320 pz](https://www.amazon.it/dp/B0DZWR53CD) 14,99 € (M3 × 5: 50, × 6: 40, × 8: 40, × 10: 30, × 16: 30; 330 dadi e 330 rondelle), più [M3 × 8 ISO 4762, 100 pz](https://www.amazon.it/dp/B07MCL1LGW) 8,73 € e [M3 × 6 DIN 912 A2, 50 pz](https://www.amazon.it/dp/B0GG6G2RJV) 8,88 € (V). Insieme: M3 × 8 140, M3 × 6 90. Alternativa con le misure esatte: Gedex 27,13 € + 25,90 € di spedizione | — | A |
| D7 | D7 | Dadi e rondelle M3 | 50 + 100 | dadi esagonali DIN 934, rondelle DIN 125 | dove un inserto non entra | nel kit di D6: 330 dadi M3 e 330 rondelle M3 | — | A |
| D8 | D8 | Viti M2 e M2,5 | assortimento | ISO 4762 inox | regolatori (M2), SSC-32 (M2,5: i suoi fori sono circa 3,0 mm) | Amazon.it: [SECCARO M2 × 5 DIN 912 A2, 20 pz](https://www.amazon.it/dp/B0D92Q2KYY), 9,43 € (V) | — | A |
| D8b | D8b | Viti M2 × 6 a testa svasata piana | 12 + 4 | ISO 10642 (DIN 7991) inox, esagono incassato; testa Ø4,0 | lame B dei femori, a filo nelle svasature (D-065, al posto delle spine stampate) | AliExpress: [M2 × 6 DIN 7991 inox 304, 50 pz](https://it.aliexpress.com/item/33028389667.html), 1,85 € (V) | — | **da approvare** |
| D9 | — | Piedini antiscivolo | 6 + 2 | stampati in TPU 95A oppure cappucci in silicone | scelta dopo una prova sui tuoi pavimenti | — | — | — |
| D10 | D10 | Fermo batteria | 1 | schiuma EVA adesiva 3–5 mm | le cinghie non servono più: lo sportello preme il pacco con due rebbi e la schiuma (D-051, approvato il 9 ottobre 2026) | Amazon.it: [fogli EVA adesivi 3 mm, 6 pz](https://www.amazon.it/dp/B0DG96T98Z), 12,99 € (V) | — | A |
| D11 | D11 | Guaina e fascette | 2 m + 1 conf. | guaina spiralata 6–8 mm, fascette 2,5 mm (tra queste 6 corte nel blocco dei femori, 6 nei ponti e 1 per F1, D-055 e D-061) | fasci dei 3 cavi per zampa, ancoraggi ai giunti | fascette: Kamami [150 × 2,5 mm, 100 pz](https://kamami.pl/opaski-zaciskowe/1191270-vorel-73893-opaski-plastikowe-150x25-100szt-czarne--5906083738937.html), 0,60 € (V); guaina: Amazon.it [GTIWUNG spiralata 6 mm](https://www.amazon.it/dp/B07WDRYFXV), 10,99 € (V) | — | A |

## Viteria e inserti contati dal modello (fase 5, bozza del 9 ottobre 2026)

Conteggio fatto in Fusion sulle lavorazioni del modello (inserti, fori pilota, fori passanti) moltiplicate per il numero di copie di ogni parte, comprese le specchiature del corpo. Lunghezze delle viti dalla pila di ogni giunto. Comprende il fissaggio del coperchio (D-052).

| Dove | Cosa | Quantità |
|---|---|---|
| Alette dei 18 servo | M3 × 8 ISO 4762: lato coda in inserti, lato albero in fori pilota Ø2,5 (D-049) | 72 |
| Femore_A → squadrette di femore e ginocchio | M3 × 6 | 48 |
| Femore_A → blocco di Femore_B | M3 × 8 con 2 rondelle M3 DIN 125 di registro ciascuna | 24 viti, 48 rondelle |
| Ponte → anima della coxa | M3 × 10 | 12 |
| Squadretta di coxa (teste che fanno da spine, D-048) | **M3 × 5**, senza rondella (D-049, da approvare) | 12 |
| Viti centrali delle squadrette | in dotazione con le squadrette | 18 |
| Chiglia → base | M3 × 16 davanti (orecchie a tutta altezza), M3 × 8 dietro | 2 + 2 |
| Slitte dei regolatori → parete della baia | M3 × 8 | 2 |
| Regolatori → slitte | M2 × 5 in inserti M2 | 8 |
| SSC-32 → bugne del tetto | M2 × 5 in inserti M2 (testa Ø3,8 sui fori da 3,0) | 4 |
| Basetta → colonnine del vassoio | M2 × 5 in inserti M2 (D-053) | 4 |
| Vassoio → distanziali | M3 × 6 sui 4 distanziali M3 maschio-femmina da 5 mm (B18) | 4 |
| Coperchio → colonnine del tetto | M3 × 8 in inserti M3 (D-052) | 4 |
| Sportello della batteria → blocchetti della chiglia | M3 × 8 in inserti M3 (D-054) | 2 |
| Guscio della tibia → stinco | M3 × 10 in inserti M3 (D-061) | 6 |
| Lama B → Femore_B | M2 × 6 a testa svasata in inserti M2 (D-065) | 12 |
| **Totale viti** | M3 × 5: 12; M3 × 6: 52; M3 × 8: 106; M3 × 10: 18; M3 × 16: 2; M2 × 5: 16; M2 × 6 svasate: 12 | |
| **Inserti a caldo** | M3: 94 (30 nel corpo, nelle gondole e nella chiglia, 24 nelle coxe, 18 nelle tibie, 24 nei femori); M2: 28 | dentro le confezioni da 200 e 50 (D4, D5) |
| Fori pilota per viti M3 autofilettanti | 36 (alette lato albero dei 18 servo) | |

Le voci D6 (viti M3 in assortimento più 100) e D8 (M2) vanno ordinate con queste quantità: in particolare servono circa 106 M3 × 8 e 52 M3 × 6, più dei pezzi di un assortimento normale.

## E. Materiali di stampa

| # | Foto | Voce | Q.tà | Uso | Nota | Acquisto (10 ottobre 2026) | Stato |
|---|---|---|---|---|---|---|---|
| E1 | E1 | PETG-CF nero | 2 bobine da 1 kg | tutte le parti funzionali: corpo (base, chiglia, slitte, sportello della batteria), zampe (coxa, ponte, femori, tibie) | circa 860 g di pezzi (stima dal modello del 9 ottobre) più provini, supporti e scarti | 3DJake.it: [eSUN PETG-CF nero 1 kg](https://www.3djake.it/esun/petg-cf-black-3), 2 × 29,49 € (V; ugello 240–260 °C) | A (scelta dell'utente, 9 ottobre 2026) |
| E2 | E2 | PLA colorato (bianco per ora) | 1 bobina | placche: carapace, lame dei femori, gusci delle tibie; vassoio dell'ESP32 (sotto l'antenna niente carbonio) | circa 230 g; il colore può cambiare | 3DJake.it: [eSUN PLA Basic bianco 1 kg](https://www.3djake.it/esun/pla-basic-white), 12,69 € (V) | A (scelta dell'utente) |
| E2b | E2b | PLA nero (o un secondo colore) | 1 bobina piccola | fascia, visiera, gonne, sportellino: stampati insieme al carapace, PLA su PLA si attacca senza interlocking | circa 15 g | 3DJake.it: [eSUN PLA Basic nero 1 kg](https://www.3djake.it/esun/pla-basic-black-1), 12,69 € (V; non ci sono bobine più piccole) | proposta (D-065) |
| E3 | E3 | TPU 95A arancio | pochi grammi | piedini (D9) | circa 10 g | 3DJake.it: [3DJAKE TPU A95 arancio 750 g](https://www.3djake.it/3djake/tpu-a95-orange), 30,49 € (V; la confezione più piccola in arancio) | A (scelta dell'utente) |

## Attrezzi necessari

Saldatore con punta per inserti a caldo (o kit di punte dedicate), multimetro, pinza spelafili, termosoffiatore o accendino per il termorestringente, chiavi a brugola da 1,5 / 2 / 2,5 mm, calibro per controllare i pezzi stampati. Al banco, per le prime accensioni: un alimentatore regolabile con limite di corrente sarebbe utile ma non indispensabile (si parte con F1 da 15 A).
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

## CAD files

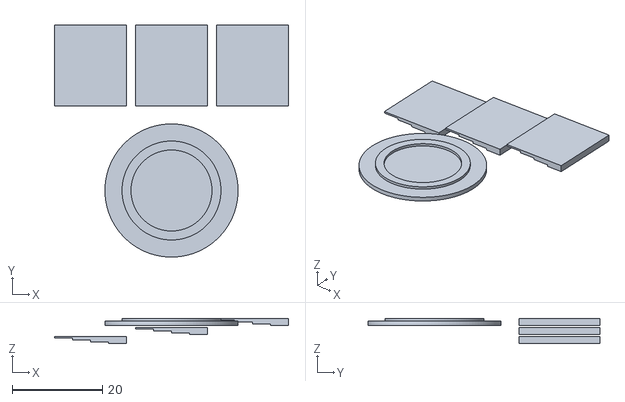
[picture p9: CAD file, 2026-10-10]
cad/stl/attrezzi/Attrezzo_Provino_Luce_Bianco.stl
52.0 x 51.6 x 5.60

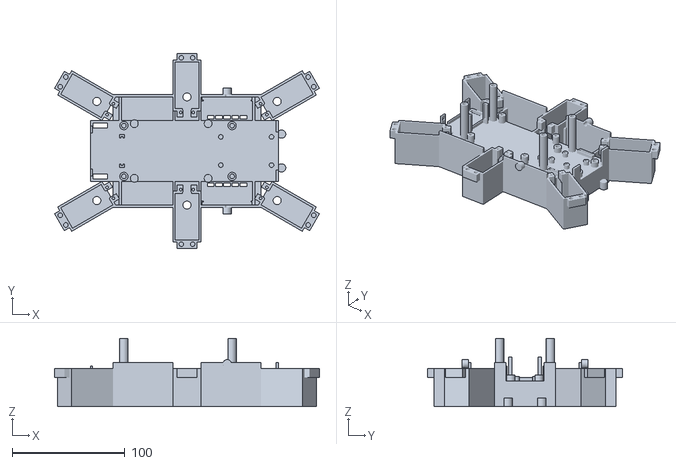
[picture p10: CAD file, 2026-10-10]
cad/stl/Corpo_Base.stl
235.1 x 172.7 x 60.4

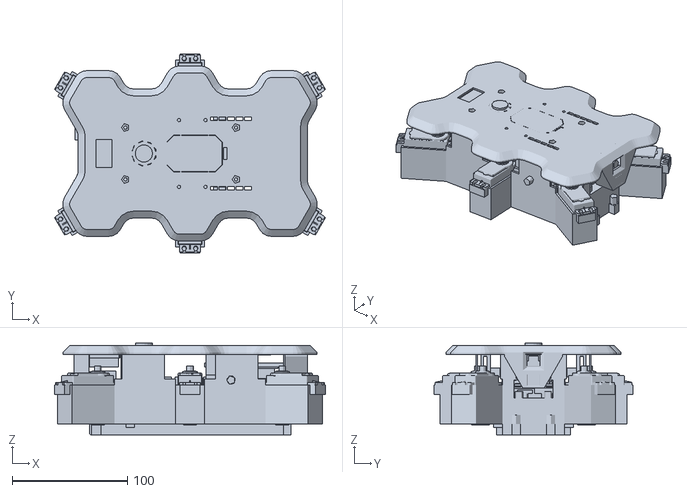
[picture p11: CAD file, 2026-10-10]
robot/mesh/corpo.stl
235.1 x 172.7 x 79.4

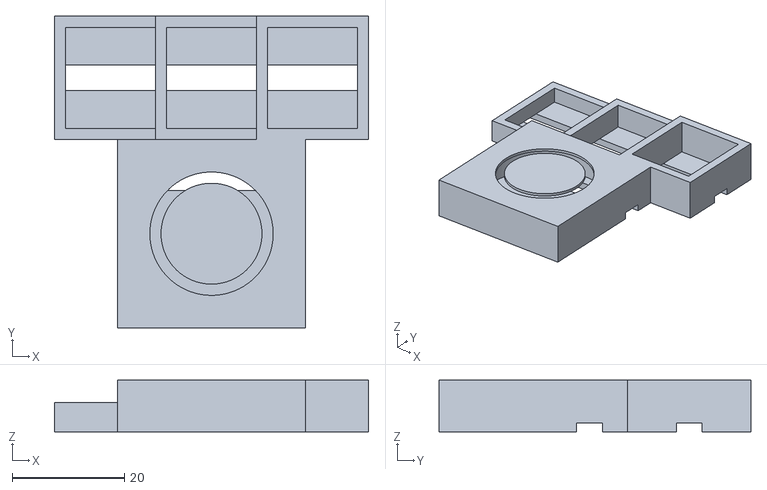
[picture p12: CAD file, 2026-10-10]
cad/stl/attrezzi/Attrezzo_Provino_Luce_Nero.stl
56.0 x 55.6 x 9.20

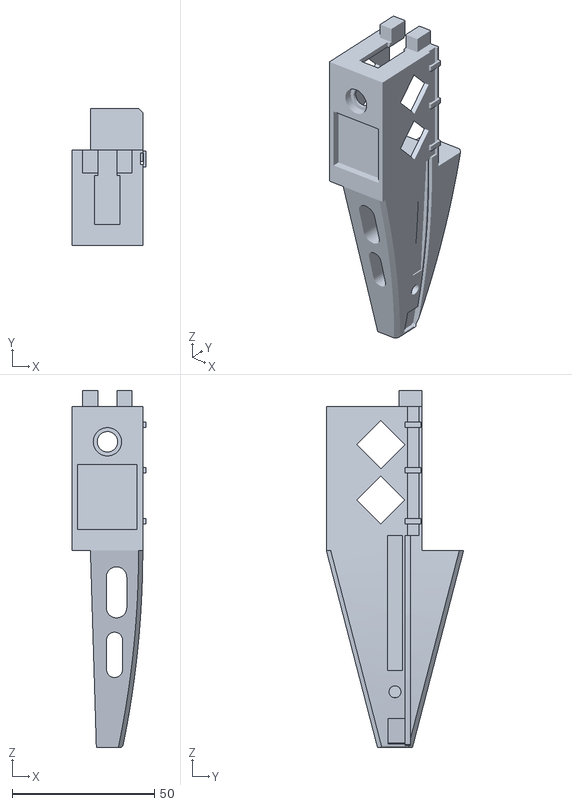
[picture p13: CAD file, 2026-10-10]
cad/stl/Tibia.stl
26.0 x 48.3 x 125.6

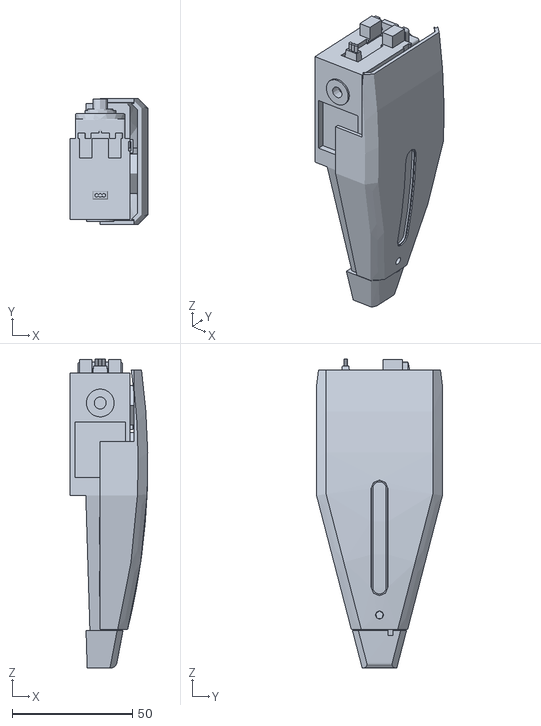
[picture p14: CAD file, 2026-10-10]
robot/mesh/tibia.stl
32.2 x 52.3 x 128.2

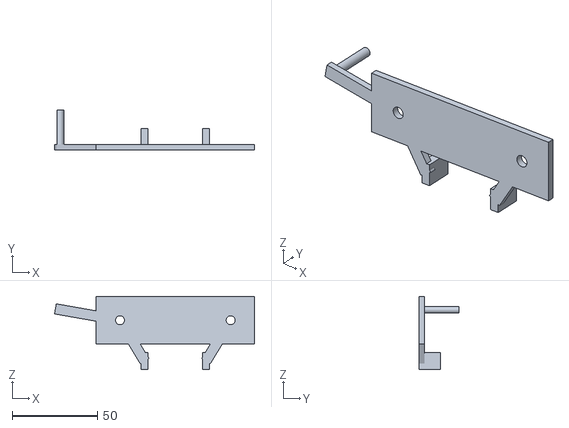
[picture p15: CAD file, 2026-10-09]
cad/stl/attrezzi/Dima_Posa_1.stl
117.5 x 23.3 x 43.0

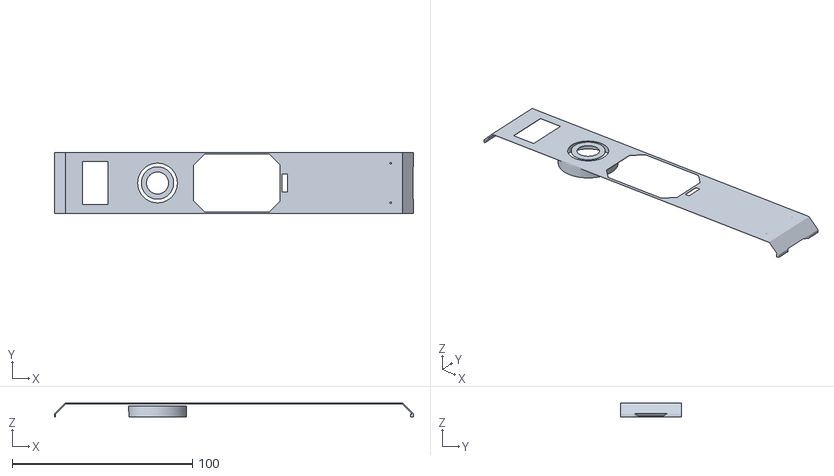
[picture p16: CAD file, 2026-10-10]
cad/stl/Corpo_Fascia.stl
199.2 x 34.0 x 7.60

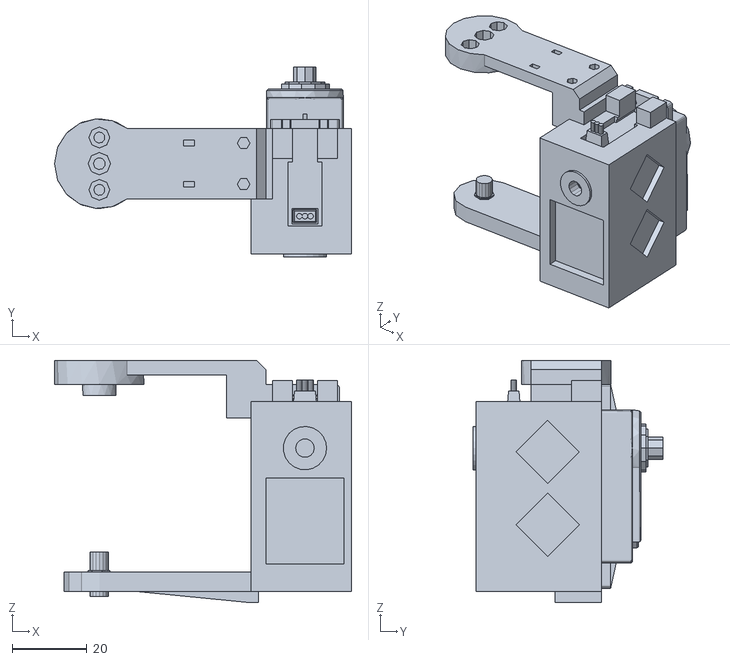
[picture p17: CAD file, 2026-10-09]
robot/mesh/coxa.stl
79.4 x 50.8 x 64.9

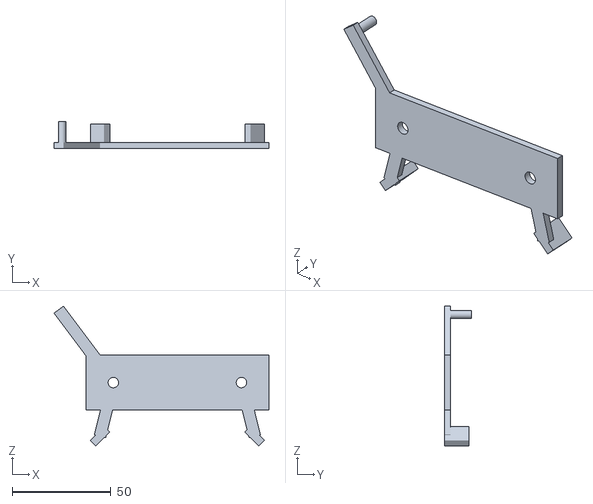
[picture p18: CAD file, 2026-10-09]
cad/stl/attrezzi/Dima_Posa_2.stl
109.1 x 13.5 x 71.0

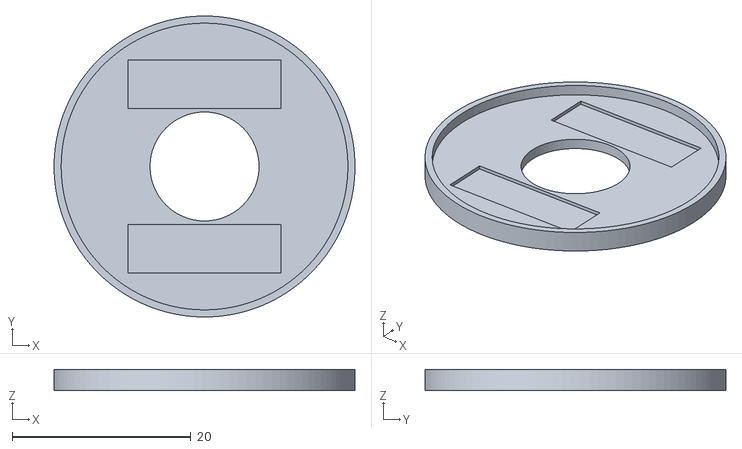
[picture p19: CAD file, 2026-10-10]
cad/stl/Corpo_Fondo_Anello.stl
33.7 x 33.7 x 2.40

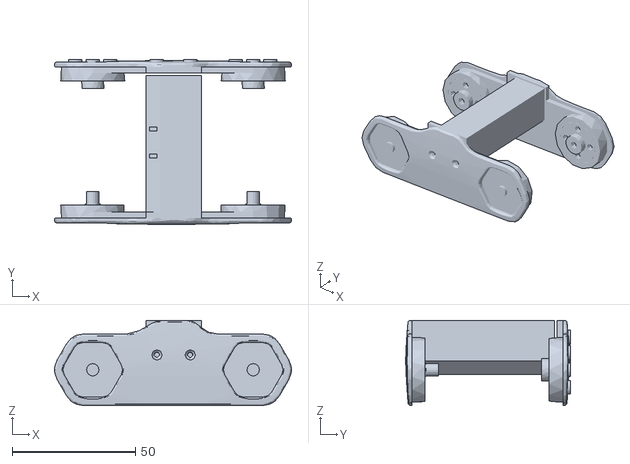
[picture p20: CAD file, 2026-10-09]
robot/mesh/femore.stl
96.0 x 66.7 x 34.5

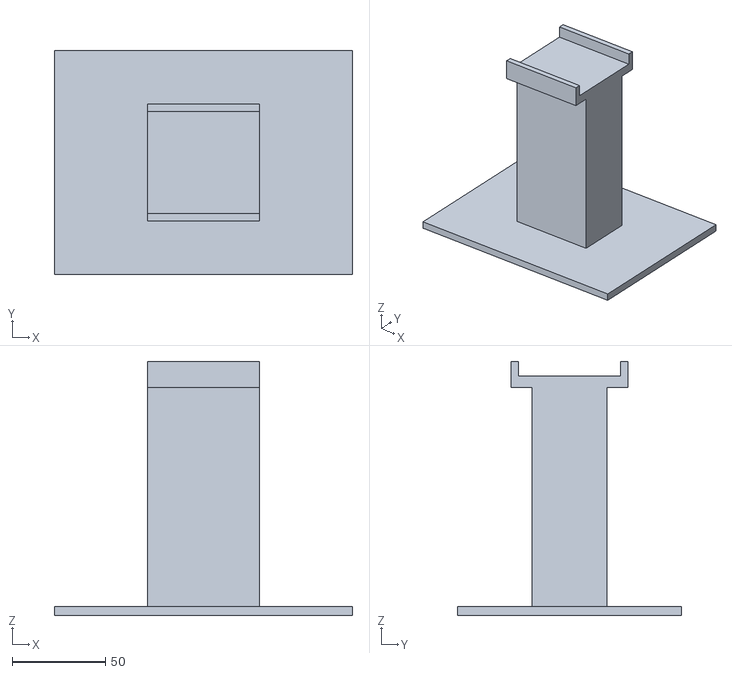
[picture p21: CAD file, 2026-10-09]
cad/stl/attrezzi/Attrezzo_Cavalletto.stl
160.0 x 120.0 x 136.6

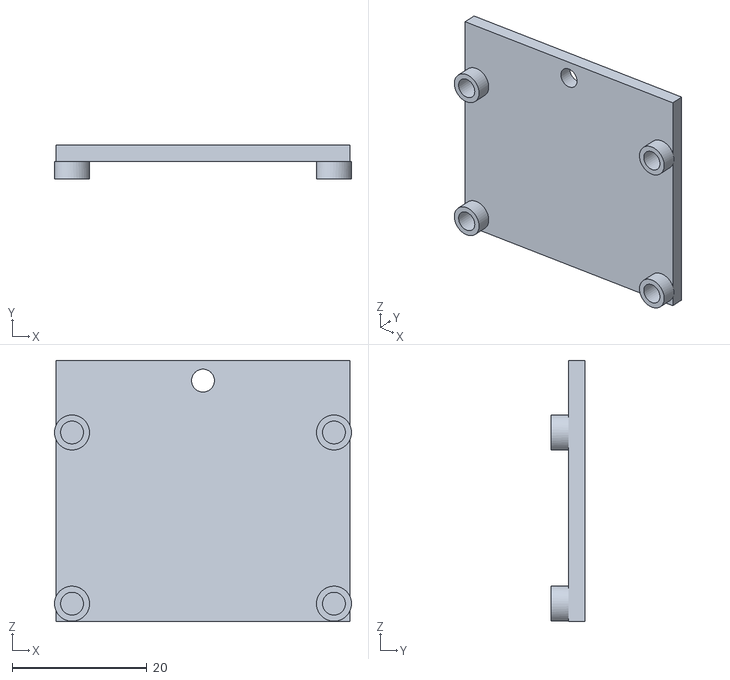
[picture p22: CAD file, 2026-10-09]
cad/stl/Corpo_Slitta_Regolatore.stl
44.1 x 5.00 x 38.8

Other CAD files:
cad/stl/Corpo_Tappo_ToF.stl
cad/stl/Corpo_Visiera.stl
cad/stl/Cover_Tibia_Diffusore.stl
cad/stl/Cover_Tibia.stl
cad/stl/Corpo_Carapace.stl
cad/stl/Corpo_Chiglia.stl
cad/stl/Corpo_Gonne.stl
cad/stl/Corpo_Sportello.stl
cad/stl/Corpo_Sportello_Servizio.stl
cad/stl/Corpo_Sportello_Servizio_Zaino.stl
cad/stl/Corpo_Supporto_INA260_D.stl
cad/stl/Corpo_Supporto_INA260_S.stl
cad/stl/Corpo_Vassoio.stl
cad/stl/Cover_Femore_A.stl
cad/stl/Cover_Femore_B.stl
cad/stl/Coxa.stl
cad/stl/Coxa_Ponte.stl
cad/stl/Femore_A.stl
cad/stl/Femore_B.stl
cad/stl/Piedino.stl

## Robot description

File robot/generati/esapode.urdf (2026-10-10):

<?xml version="1.0"?>
<robot name="esapode">
  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
  <link name="corpo">
    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
    <inertial>
      <origin xyz="0.004479 0.000008 -0.010686" rpy="0 0 0" />
      <mass value="1.42791" />
      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
    </inertial>
    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
  </link>
  <link name="imu" />
  <joint name="imu" type="fixed">
    <parent link="corpo" />
    <child link="imu" />
    <origin xyz="0.0525 0 -0.0059" rpy="0 0 0" />
  </joint>
  <link name="coxa_AS">
    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
    <inertial>
      <origin xyz="0.046381 -0.001983 -0.009636" rpy="0 0 0" />
      <mass value="0.09408" />
      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
    </inertial>
    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
  </link>
  <link name="femore_AS">
    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
    <inertial>
      <origin xyz="0.03256 0.003123 0.003408" rpy="0 0 0" />
      <mass value="0.05442" />
      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
    </inertial>
    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
  </link>
  <link name="tibia_AS">
    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
    <inertial>
      <origin xyz="0.002576 -0.001438 -0.02751" rpy="0 0 0" />
      <mass value="0.11189" />
      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
    </inertial>
    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
  </link>
  <link name="piede_AS" />
  <joint name="g_coxa_AS" type="revolute">
    <parent link="corpo" />
    <child link="coxa_AS" />
    <origin xyz="0.08 0.044 0" rpy="0 0 0.523598776" />
    <axis xyz="0 0 1" />
    <limit lower="-0.610865" upper="0.610865" effort="1.0787" velocity="7.48" />
    <dynamics damping="0.144216" />
  </joint>
  <joint name="g_femore_AS" type="revolute">
    <parent link="coxa_AS" />
    <child link="femore_AS" />
    <origin xyz="0.055 0 0" rpy="0 0 0" />
    <axis xyz="0 -1 0" />
    <limit lower="-0.855211" upper="1.48353" effort="1.0787" velocity="7.48" />
    <dynamics damping="0.144216" />
  </joint>
  <joint name="g_ginocchio_AS" type="revolute">
    <parent link="femore_AS" />
    <child link="tibia_AS" />
    <origin xyz="0.065 0 0" rpy="0 0 0" />
    <axis xyz="0 -1 0" />
    <limit lower="-1.064651" upper="1.570796" effort="1.0787" velocity="7.48" />
    <dynamics damping="0.144216" />
  </joint>
  <joint name="punta_AS" type="fixed">
    <parent link="tibia_AS" />
    <child link="piede_AS" />
    <origin xyz="0 0 -0.11" rpy="0 0 0" />
  </joint>
  <link name="coxa_MS">
    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
    <inertial>
      <origin xyz="0.046381 -0.001983 -0.009636" rpy="0 0 0" />
      <mass value="0.09408" />
      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
    </inertial>
    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
  </link>
  <link name="femore_MS">
    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
    <inertial>
      <origin xyz="0.03256 0.003123 0.003408" rpy="0 0 0" />
      <mass value="0.05442" />
      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
    </inertial>
    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
  </link>
  <link name="tibia_MS">
    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
    <inertial>
      <origin xyz="0.002576 -0.001438 -0.02751" rpy="0 0 0" />
      <mass value="0.11189" />
      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
    </inertial>
    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
  </link>
  <link name="piede_MS" />
  <joint name="g_coxa_MS" type="revolute">
    <parent link="corpo" />
    <child link="coxa_MS" />
    <origin xyz="0 0.048 0" rpy="0 0 1.570796327" />
    <axis xyz="0 0 1" />
    <limit lower="-0.610865" upper="0.610865" effort="1.0787" velocity="7.48" />
    <dynamics damping="0.144216" />
  </joint>
  <joint name="g_femore_MS" type="revolute">
    <parent link="coxa_MS" />
    <child link="femore_MS" />
    <origin xyz="0.055 0 0" rpy="0 0 0" />
    <axis xyz="0 -1 0" />
    <limit lower="-0.855211" upper="1.48353" effort="1.0787" velocity="7.48" />
    <dynamics damping="0.144216" />
  </joint>
  <joint name="g_ginocchio_MS" type="revolute">
    <parent link="femore_MS" />
    <child link="tibia_MS" />
    <origin xyz="0.065 0 0" rpy="0 0 0" />
    <axis xyz="0 -1 0" />
    <limit lower="-1.064651" upper="1.570796" effort="1.0787" velocity="7.48" />
    <dynamics damping="0.144216" />
  </joint>
  <joint name="punta_MS" type="fixed">
    <parent link="tibia_MS" />
    <child link="piede_MS" />
    <origin xyz="0 0 -0.11" rpy="0 0 0" />
  </joint>
  <link name="coxa_PS">
    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
    <inertial>
      <origin xyz="0.046381 -0.001983 -0.009636" rpy="0 0 0" />
      <mass value="0.09408" />
      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
    </inertial>
    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
  </link>
  <link name="femore_PS">
    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
    <inertial>
      <origin xyz="0.03256 0.003123 0.003408" rpy="0 0 0" />
      <mass value="0.05442" />
      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
    </inertial>
    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
  </link>
  <link name="tibia_PS">
    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
    <inertial>
      <origin xyz="0.002576 -0.001438 -0.02751" rpy="0 0 0" />
      <mass value="0.11189" />
      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
    </inertial>
    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
  </link>
  <link name="piede_PS" />
  <joint name="g_coxa_PS" type="revolute">
    <parent link="corpo" />
    <child link="coxa_PS" />
    <origin xyz="-0.08 0.044 0" rpy="0 0 2.617993878" />
    <axis xyz="0 0 1" />
    <limit lower="-0.610865" upper="0.610865" effort="1.0787" velocity="7.48" />
    <dynamics damping="0.144216" />
  </joint>
  <joint name="g_femore_PS" type="revolute">
    <parent link="coxa_PS" />
    <child link="femore_PS" />
    <origin xyz="0.055 0 0" rpy="0 0 0" />
    <axis xyz="0 -1 0" />
    <limit lower="-0.855211" upper="1.48353" effort="1.0787" velocity="7.48" />
    <dynamics damping="0.144216" />
  </joint>
  <joint name="g_ginocchio_PS" type="revolute">
    <parent link="femore_PS" />
    <child link="tibia_PS" />
    <origin xyz="0.065 0 0" rpy="0 0 0" />
    <axis xyz="0 -1 0" />
    <limit lower="-1.064651" upper="1.570796" effort="1.0787" velocity="7.48" />
    <dynamics damping="0.144216" />
  </joint>
  <joint name="punta_PS" type="fixed">
    <parent link="tibia_PS" />
    <child link="piede_PS" />
    <origin xyz="0 0 -0.11" rpy="0 0 0" />
  </joint>
  <link name="coxa_AD">
    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
    <inertial>
      <origin xyz="0.046381 -0.001983 -0.009636" rpy="0 0 0" />
      <mass value="0.09408" />
      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
    </inertial>
    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
  </link>
  <link name="femore_AD">
    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
    <inertial>
      <origin xyz="0.03256 0.003123 0.003408" rpy="0 0 0" />
      <mass value="0.05442" />
      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
    </inertial>
    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
  </link>
  <link name="tibia_AD">
    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
    <inertial>
      <origin xyz="0.002576 -0.001438 -0.02751" rpy="0 0 0" />
      <mass value="0.11189" />
      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
    </inertial>
    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
  </link>
  <link name="piede_AD" />
  <joint name="g_coxa_AD" type="revolute">
    <parent link="corpo" />
    <child link="coxa_AD" />
    <origin xyz="0.08 -0.044 0" rpy="0 0 -0.523598776" />
    <axis xyz="0 0 1" />
    <limit lower="-0.610865" upper="0.610865" effort="1.0787" velocity="7.48" />
    <dynamics damping="0.144216" />
  </joint>
  <joint name="g_femore_AD" type="revolute">
    <parent link="coxa_AD" />
    <child link="femore_AD" />
    <origin xyz="0.055 0 0" rpy="0 0 0" />
    <axis xyz="0 -1 0" />
    <limit lower="-0.855211" upper="1.48353" effort="1.0787" velocity="7.48" />
    <dynamics damping="0.144216" />
  </joint>
  <joint name="g_ginocchio_AD" type="revolute">
    <parent link="femore_AD" />
    <child link="tibia_AD" />
    <origin xyz="0.065 0 0" rpy="0 0 0" />
    <axis xyz="0 -1 0" />
    <limit lower="-1.064651" upper="1.570796" effort="1.0787" velocity="7.48" />
    <dynamics damping="0.144216" />
  </joint>
  <joint name="punta_AD" type="fixed">
    <parent link="tibia_AD" />
    <child link="piede_AD" />
    <origin xyz="0 0 -0.11" rpy="0 0 0" />
  </joint>
  <link name="coxa_MD">
    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
    <inertial>
      <origin xyz="0.046381 -0.001983 -0.009636" rpy="0 0 0" />
      <mass value="0.09408" />
      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
    </inertial>
    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
  </link>
  <link name="femore_MD">
    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
    <inertial>
      <origin xyz="0.03256 0.003123 0.003408" rpy="0 0 0" />
      <mass value="0.05442" />
      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
    </inertial>
    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
  </link>
  <link name="tibia_MD">
    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
    <inertial>
      <origin xyz="0.002576 -0.001438 -0.02751" rpy="0 0 0" />
      <mass value="0.11189" />
      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
    </inertial>
    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
  </link>
  <link name="piede_MD" />
  <joint name="g_coxa_MD" type="revolute">
    <parent link="corpo" />
    <child link="coxa_MD" />
    <origin xyz="0 -0.048 0" rpy="0 0 -1.570796327" />
    <axis xyz="0 0 1" />
    <limit lower="-0.610865" upper="0.610865" effort="1.0787" velocity="7.48" />
    <dynamics damping="0.144216" />
  </joint>
  <joint name="g_femore_MD" type="revolute">
    <parent link="coxa_MD" />
    <child link="femore_MD" />
    <origin xyz="0.055 0 0" rpy="0 0 0" />
    <axis xyz="0 -1 0" />
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

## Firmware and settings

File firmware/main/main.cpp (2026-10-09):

// Firmware dell'esapode (software.md 2). Per ora: rail spento, autotest del nucleo, compiti di 2.2 come scheletri.
#include <cmath>

#include "compiti.hpp"
#include "driver/gpio.h"
#include "esp_log.h"
#include "nucleo/nucleo.hpp"

namespace {

const char* const TAG = "hexapod";

// Accensione del rail dei servo: spento con il GPIO basso o flottante (D-019, software.md 2.6).
constexpr gpio_num_t GPIO_RAIL = GPIO_NUM_42;

void rail_spento() {
    ESP_ERROR_CHECK(gpio_set_level(GPIO_RAIL, 0));  // il livello prima della direzione: niente impulsi alti
    gpio_config_t io = {};
    io.pin_bit_mask = 1ULL << GPIO_RAIL;
    io.mode = GPIO_MODE_OUTPUT;
    io.pull_up_en = GPIO_PULLUP_DISABLE;
    io.pull_down_en = GPIO_PULLDOWN_DISABLE;
    io.intr_type = GPIO_INTR_DISABLE;
    ESP_ERROR_CHECK(gpio_config(&io));
    ESP_ERROR_CHECK(gpio_set_level(GPIO_RAIL, 0));
}

// Il nucleo calcola la posa iniziale dell'andatura di riferimento e la guardia la deve accettare.
bool autotest_nucleo() {
    nucleo::ParametriAndatura par;
    par.passo_x = nucleo::robot::andatura::passo;
    nucleo::Posa posa{};
    if (!nucleo::pose_tripode(par, 0.0f, posa)) {
        ESP_LOGE(TAG, "autotest: posa iniziale fuori portata, controllare robot_generato.hpp");
        return false;
    }
    const nucleo::Esito e = nucleo::Guardia().controlla({posa, nucleo::appoggio_tripode(0.0f)}, nullptr, 0.0f);
    if (!e.accettato) {
        ESP_LOGE(TAG, "autotest: la guardia rifiuta la posa iniziale (%s, zampa %d)", nucleo::nome_motivo(e.motivo),
                 e.zampa);
        return false;
    }
    // niente %f nei log: interi, cosi' non serve il printf con la virgola mobile
    ESP_LOGI(TAG, "autotest del nucleo: posa iniziale accettata, coppia stimata %d %% dello stallo, margine %d mm",
             static_cast<int>(std::lround(e.coppia_max * 100.0f)), static_cast<int>(std::lround(e.margine_stabilita_mm)));
    return true;
}

}  // namespace

extern "C" void app_main(void) {
    rail_spento();
    ESP_LOGI(TAG, "esapode %s, CAD \"%s\" (cad.json %.12s)", nucleo::robot::versione, nucleo::robot::documento_cad,
             nucleo::robot::cad_sha256);
    if (!autotest_nucleo()) {
        ESP_LOGE(TAG, "rail spento e compiti non avviati: il firmware non e' coerente con la descrizione del robot");
        return;
    }
    avvia_compiti();
}

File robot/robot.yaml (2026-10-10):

# Descrizione unica del robot (versione 2.1.2): la parte scritta a mano. La geometria, le masse e i limiti meccanici
# stanno in cad.json, esportato dal modello Fusion con cad/script/esporta_robot.py; tools/descrizione.py unisce i
# due file, tools/genera_header.py ne fa l'header del firmware, tools/genera_modelli.py URDF e MJCF. Il CI controlla che cad_sha256 sia quello di
# cad.json: se si riesporta dal CAD, si aggiorna anche qui (e si rigenera).
#
# Unita': mm, g, gradi, microsecondi. Terne e angoli come in cad.json:
#   robot  X avanti, Y a sinistra, Z in alto; origine al centro del corpo, all'altezza degli assi dei femori
#   zampa  X verso l'esterno lungo la direzione neutra, Y verso Femore_A, Z in alto (le sei zampe sono la stessa
#          zampa ruotata, non specchiata: versi e limiti valgono uguali per tutte)
#   imbardata attorno a +Z dalla direzione neutra; alpha del femore sopra l'orizzontale; gamma angolo interno al
#   ginocchio (180 = distesa). Cinematica: calc/statica_tripode.py -> ik_piano (soluzione a ginocchio alto).
# Stato dei dati: V verificato, S stimato, C da confermare (come nei documenti).

versione: 2.1.2
cad: cad.json
cad_sha256: 97f183e2b3887a5db45f1f3ca61af3e546bc48d0271c0da17b2f8a54a2997708  # impronta di cad.json: python3 tools/descrizione.py --aggiorna-hash dopo ogni esportazione

zampe: [AS, MS, PS, AD, MD, PD]          # A anteriore, M media, P posteriore; S sinistra, D destra
tripodi: [[AS, PS, MD], [AD, PD, MS]]    # calc/statica_tripode.py -> TRIPODI
vicine: [[AS, MS], [MS, PS], [AD, MD], [MD, PD]]

# Canali della SSC-32 (C, proposta): le zampe anteriori sui canali verso la morsettiera (avanti), come
# calc/cavi_servo.py -> ASSEGNA; lato sinistro 0-15, destro 16-31. Il lato dei canali 0-15 sulla scheda montata
# (morsettiera in avanti) va controllato sull'ingombro Rif_SSC32_V25 e al banco (passo B1).
canali:
  AS: {coxa: 0, femore: 1, ginocchio: 2}
  MS: {coxa: 6, femore: 7, ginocchio: 8}
  PS: {coxa: 13, femore: 14, ginocchio: 15}
  AD: {coxa: 16, femore: 17, ginocchio: 18}
  MD: {coxa: 22, femore: 23, ginocchio: 24}
  PD: {coxa: 29, femore: 30, ginocchio: 31}

servo:
  modello: MG996R AZDelivery
  stallo_kgfcm: {4.8: 9.4, 6.0: 11.0}    # V, datasheet AZDelivery
  velocita_s_60: {4.8: 0.17, 6.0: 0.14}  # V, a vuoto
  tensione_rail: 6.0
  periodo_ms: 20                         # V
  banda_morta_us: 5                      # V
  centro_us: 1500                        # S, standard
  us_per_grado: 11.1                     # S: 500-2500 us su circa 180 gradi; la taratura con le dime lo sostituisce
  corsa_gradi: 160                       # utile, su 180 nominali (calc/statica_tripode.py -> CONFIG)
  # verso = segno di d(angolo del giunto)/d(impulso). Ipotesi (C, da provare al passo B2): il servo gira in senso
  # antiorario attorno al proprio albero quando l'impulso cresce. Alberi: coxa verso +Z, femore e ginocchio verso
  # +Y della zampa (zampa.py -> ASSI_SERVO); il ginocchio ha la cassa nella tibia e la squadretta sul femore.
  verso: {coxa: 1, femore: -1, ginocchio: 1}
  # calettamento: angolo del giunto con il servo a centro_us (software.md 2.5): corsa del servo +-80 attorno
  calettamento: {imbardata: 0.0, alpha: 20.0, gamma: 100.0}

# Limiti del firmware (guardia, software.md 2.5). Quelli meccanici sono in cad.json -> limiti_meccanici.
guardia:
  imbardata: [-30.0, 30.0]               # fine corsa 35; contatto tra vicine fra 31 e 32 ciascuna (D-061, D-063)
  # somma tra vicine (proposta): a sinistra imb_A - imb_M e imb_M - imb_P, a destra il contrario; 56 lascia 3 gradi
  # per zampa come al ginocchio. Da approvare: cambia D-050 e D-061 (oggi 60)
  somma_vicine: 56.0
  alpha: [-45.0, 82.0]                   # campo libero -49...85 meno 3; la tabella del ginocchio parte da -45
  gamma_max: 177.0
  gamma_margine: 3.0                     # sopra cad.json -> limiti_meccanici.gamma_min(alpha)
  # fra due righe della tabella vale il massimo dei due valori: la tabella non e' monotona (-40 -> 55, -35 -> 45)
  gamma_min_interpolazione: massimo
  corsa_servo: 80.0                      # +- attorno al calettamento
  velocita_gradi_s: 250.0                # proposta; a vuoto 429 (V)
  coppia_avviso: 0.55                    # frazione dello stallo (proposte)
  coppia_tempo_limitato: 0.60
  coppia_rifiuto: 0.70
  stabilita_mm: 20.0                     # baricentro dai lati del poligono d'appoggio (proposta)
  # se un fotogramma viola un limite non si tronca il giunto (il piede striscerebbe): si riduce il comando e si
  # ricalcola; se non basta si tiene il fotogramma precedente e si registra l'evento
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

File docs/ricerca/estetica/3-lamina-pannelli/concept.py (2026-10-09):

"""Render schematici del concept "Lamina" (angolo: pannelli) sul modello attuale dell'esapode MG996R.

Uso:  python3 concept.py            -> tutte le viste
      python3 concept.py iso_ant    -> solo le viste nominate (per le prove)

Quote dal concept (mm, terna del robot; le parti di zampa nella terna della zampa, posa di riferimento).
Le fughe d'ombra (larghe 0,5-1 mm) sono disegnate con il loro fondo in un colore d'ombra, perche' il render
non calcola ombre portate: senza, una fuga larga 1 px sparirebbe.
"""
import math
import os
import sys

import numpy as np
from matplotlib.path import Path
from scipy.spatial import ConvexHull, Delaunay, cKDTree

sys.path.insert(0, '/Users/paul/.claude/jobs/3d86073b/tmp/estetica')
import render as R  # noqa: E402

QUI = os.path.dirname(os.path.abspath(__file__))
OUT = os.path.join(QUI, 'pannelli')

# ----------------------------------------------------------------------------------- colori del concept
NERO = '#27292c'        # PETG-CF nero naturale: struttura del corpo e delle zampe
SERVO = '#18181b'       # servo MG996R, squadrette, cuscinetti, perni
ANTRACITE = '#454c53'   # PETG tipo RAL 7016: carapace (spina, bordo, frontale, gonne, guance), sportelli
GRIGIO = '#c9cdca'      # PETG tipo RAL 7035: lamine delle spalle e cover di zampa
ARANCIO = '#f04e14'     # PETG tipo RAL 2004: anello dell'occhio e del pulsante
OMBRA = '#0e0f11'       # fondo delle fughe d'ombra
DISPLAY = '#d6242b'     # display rosso del cicalino
METALLO = '#a5a9ad'     # testa del pulsante da pannello
VITE = '#1c1d1f'        # teste delle viti (acciaio brunito)
INTERNI = '#4e545b'
CICALINO = '#1f2023'


# ----------------------------------------------------------------------------------- geometria 2D
def _area2(p):
    return sum(p[i][0] * p[(i + 1) % len(p)][1] - p[(i + 1) % len(p)][0] * p[i][1] for i in range(len(p)))


def _cr(o, a, b):
    return (a[0] - o[0]) * (b[1] - o[1]) - (a[1] - o[1]) * (b[0] - o[0])


def _in_tri(p, a, b, c, eps=1e-9):
    return _cr(a, b, p) >= -eps and _cr(b, c, p) >= -eps and _cr(c, a, p) >= -eps


def _incrocia(p1, p2, q1, q2):
    d1, d2 = _cr(q1, q2, p1), _cr(q1, q2, p2)
    d3, d4 = _cr(p1, p2, q1), _cr(p1, p2, q2)
    return d1 * d2 < 0 and d3 * d4 < 0


def _in_cono(a0, a, a1, b):
    """b e' dentro l'angolo interno del vertice a (poligono antiorario, a0 precedente, a1 successivo)?"""
    if _cr(a, a1, a0) >= 0:                       # vertice convesso
        return _cr(a, b, a0) > 0 and _cr(b, a, a1) > 0
    return not (_cr(a, b, a1) >= 0 and _cr(b, a, a0) >= 0)


def _ponte(poly, foro, altri):
    """Unisce un foro (orario) al contorno (antiorario) con un ponte verso il vertice visibile piu' vicino."""
    j = max(range(len(foro)), key=lambda k: foro[k][0])
    m = foro[j]
    for i in sorted(range(len(poly)), key=lambda i: (poly[i][0] - m[0]) ** 2 + (poly[i][1] - m[1]) ** 2):
        p = poly[i]
        if not _in_cono(poly[i - 1], p, poly[(i + 1) % len(poly)], m):
            continue
        libero = True
        for anello in [poly, foro] + altri:
            n = len(anello)
            if any(_incrocia(m, p, anello[k], anello[(k + 1) % n]) for k in range(n)):
                libero = False
                break
        if libero:
            return poly[:i + 1] + foro[j:] + foro[:j + 1] + poly[i:]
    raise RuntimeError('nessun ponte per il foro in %s' % (m,))


def antiorario(p):
    p = [tuple(map(float, q)) for q in p]
    return p if _area2(p) > 0 else p[::-1]


def triangola(contorno, fori=()):
    """Triangolazione a orecchie di un poligono semplice con fori (contorno e fori in qualunque verso)."""
    poly = antiorario(contorno)
    hs = [antiorario(h)[::-1] for h in fori]
    hs.sort(key=lambda h: -max(q[0] for q in h))
    for k, h in enumerate(hs):
        poly = _ponte(poly, h, hs[k + 1:])
    idx = list(range(len(poly)))
    tris = []
    while len(idx) > 3:
        n = len(idx)
        preso = False
        for k in range(n):
            i0, i1, i2 = idx[k - 1], idx[k], idx[(k + 1) % n]
            a, b, c = poly[i0], poly[i1], poly[i2]
            if _cr(a, b, c) <= 1e-10:
                continue
            if any(_in_tri(poly[m], a, b, c) for m in idx
                   if m not in (i0, i1, i2) and poly[m] not in (a, b, c)):
                continue
            tris.append((a, b, c))
            idx.pop(k)
            preso = True
            break
        if not preso:          # restano solo vertici allineati: si toglie quello piu' piatto
            k = min(range(n), key=lambda k: abs(_cr(poly[idx[k - 1]], poly[idx[k]], poly[idx[(k + 1) % n]])))
            idx.pop(k)
    tris.append(tuple(poly[i] for i in idx))
    return tris


def _campiona(anello, passo):
    out = []
    n = len(anello)
    for k in range(n):
        a, b = anello[k], anello[(k + 1) % n]
        m = max(1, int(math.ceil(math.hypot(b[0] - a[0], b[1] - a[1]) / passo)))
        out += [(a[0] + (b[0] - a[0]) * j / m, a[1] + (b[1] - a[1]) * j / m) for j in range(m)]
    return out


def triangola_fine(contorno, fori=(), passo=7.5, bordo=0.8):
    """Triangoli quasi equilateri (reticolo interno + bordo fitto, Delaunay filtrato): sulle facce grandi evita i
    ventagli di triangoli lunghi, che nel render a pittore lasciano righe chiare sulle superfici piane."""
    anelli = [antiorario(contorno)] + [antiorario(h) for h in fori]
    bordo_pt = np.array(sum((_campiona(a, bordo) for a in anelli), []))
    out_p, fori_p = Path(np.array(anelli[0])), [Path(np.array(h)) for h in anelli[1:]]
    lo, hi = np.array(anelli[0]).min(0), np.array(anelli[0]).max(0)
    gy = np.arange(lo[1], hi[1], passo * 0.866)
    griglia = np.array([(x + (passo / 2 if i % 2 else 0), y) for i, y in enumerate(gy) for x in np.arange(lo[0], hi[0], passo)])

    def dentro(q):
        ok = out_p.contains_points(q)
        for h in fori_p:
            ok &= ~h.contains_points(q)
        return ok
    if len(griglia):
        griglia = griglia[dentro(griglia)]
    if len(griglia):
        griglia = griglia[cKDTree(bordo_pt).query(griglia)[0] > 0.5 * passo]
    pts = np.vstack([bordo_pt, griglia]) if len(griglia) else bordo_pt
    tri = pts[Delaunay(pts).simplices]
    tri = tri[dentro(tri.mean(1))]
    return [tuple(map(tuple, t)) for t in tri]
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

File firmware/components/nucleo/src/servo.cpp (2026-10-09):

#include "nucleo/servo.hpp"

#include <cmath>

namespace nucleo {

Taratura taratura_predefinita() {
    Taratura t{};
    for (size_t z = 0; z < N_ZAMPE; ++z) {
        for (size_t j = 0; j < N_GIUNTI; ++j) {
            t[z][j] = {robot::servo::canali[z][j], robot::servo::verso[j], robot::servo::centro_us,
                       robot::servo::us_per_grado, robot::servo::calettamento[j]};
        }
    }
    return t;
}

float angolo_a_us(const TaraturaGiunto& t, float angolo) {
    return t.centro_us + static_cast<float>(t.verso) * t.us_per_grado * (angolo - t.calettamento);
}

float us_a_angolo(const TaraturaGiunto& t, float us) {
    return t.calettamento + (us - t.centro_us) / (static_cast<float>(t.verso) * t.us_per_grado);
}

void posa_a_impulsi(const Taratura& t, const Posa& p, Impulsi& out) {
    for (size_t z = 0; z < N_ZAMPE; ++z) {
        for (size_t j = 0; j < N_GIUNTI; ++j) {
            const float us = angolo_a_us(t[z][j], angolo(p[z], static_cast<int>(j)));
            out[z][j] = static_cast<uint16_t>(std::lround(us));
        }
    }
}

ModelloServo::ModelloServo(float velocita_gradi_s, float banda_morta_gradi)
    : velocita_gradi_s_(velocita_gradi_s), banda_morta_gradi_(banda_morta_gradi) {}

void ModelloServo::reimposta(float angolo) { previsto_ = angolo; }

float ModelloServo::aggiorna(float comando, float dt_s) {
    const float errore = comando - previsto_;
    if (std::fabs(errore) <= banda_morta_gradi_) {
        return previsto_;
    }
    const float passo = velocita_gradi_s_ * dt_s;
    previsto_ += errore > passo ? passo : (errore < -passo ? -passo : errore);
    return previsto_;
}

ModelloPosa::ModelloPosa(const Taratura& t) {
    const float velocita = 60.0f / robot::servo::velocita_s_60;
    for (size_t z = 0; z < N_ZAMPE; ++z) {
        for (size_t j = 0; j < N_GIUNTI; ++j) {
            servo_[z][j] = ModelloServo(velocita, robot::servo::banda_morta_us / t[z][j].us_per_grado);
        }
    }
}

void ModelloPosa::reimposta(const Posa& p) {
    prevista_ = p;
    for (size_t z = 0; z < N_ZAMPE; ++z) {
        for (size_t j = 0; j < N_GIUNTI; ++j) {
            servo_[z][j].reimposta(angolo(p[z], static_cast<int>(j)));
        }
    }
}

const Posa& ModelloPosa::aggiorna(const Posa& comando, float dt_s) {
    for (size_t z = 0; z < N_ZAMPE; ++z) {
        for (size_t j = 0; j < N_GIUNTI; ++j) {
            angolo(prevista_[z], static_cast<int>(j)) =
                servo_[z][j].aggiorna(angolo(comando[z], static_cast<int>(j)), dt_s);
        }
    }
    return prevista_;
}

}  // namespace nucleo

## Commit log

2026-10-08 Fasi 1-3: studio dei componenti, BOM v1.2, dimensionamento e modelli di riferimento
    Studio dei componenti (fase 1)
    - Ricerca su 7 temi con verifica indipendente su fonte primaria (research_notes/)
    e report di sintesi (reports/).
    - Servo Tower Pro MG90S: 2S diretta esclusa, rail a 6,0 V, stallo di progetto
    1,0 A per servo, coppia di progetto 2,0 kgf*cm a 6,0 V.
    BOM e revisione (fase 2)
    - BOM v1.2 approvato: due regolatori Pololu D42V110F6 (uno per lato della
    SSC-32), rail servo spento di default e acceso dai pin di abilitazione,
    logica separata, batteria OVONIC 2S 2200 mAh.
    - Revisione indipendente del BOM v1 (elettrico, meccanico, acquisti): 47 rilievi
    integrati (docs/revisioni/).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
    [rif_componenti.py]
2026-10-08 Fase 4 (CAD): zampa v0 modellata e verificata, piano del corpo
    - cad/script/lib_cad.py: schizzi completamente vincolati via API (rettangolo,
    cerchio, blocco, cilindro, svuotamento). Il poligono non funziona ancora:
    diagnosi annotata in CLAUDE.md.
    - cad/script/zampa.py: parametri, parti Coxa / Femore_A / Femore_B / Tibia,
    istanze di servo, cuscinetti e perni, giunti rigidi e di rivoluzione.
    - cad/script/verifica_zampa.py: scansione femore x ginocchio pilotando i giunti
    veri, con controllo delle interferenze.
    - docs/progetto-meccanico.md: architettura della zampa com'e' costruita, esito
    della verifica, rifiniture da fare, disposizione proposta per il corpo.
    - Decisioni D-032...D-035;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
    [zampa.py]
2026-10-08 Fase 4 (CAD): corpo v0, assieme con sei zampe, due modi di marcia
    - Corpo: base a vasca con gondole, tunnel della batteria, paratia, nervature,
    linguette e tasche dei dadi; guscio sfaccettato da 1,6 mm fissato con otto
    viti M2; vassoio dell'ESP32; sportelli a incastro; torretta della camera.
    - Assieme: corpo fissato, sei zampe, giunti delle coxe, servo di coxa ed
    elettronica; interferenze, massa e baricentro; pose per istanza.
    - Zampa: femore con puntone al posto dell'anima piena (ginocchio 50-145 gradi,
    femore da -60 a +55); limiti dei giunti come passo a parte.
    - Due modi di marcia (D-039): alto e raccolto, basso e largo; ciclo a tripode
    verificato senza interferenze in entrambi.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
    [zampa.py]
2026-10-08 main diventa la versione MG996R; la versione MG90S va in archivio
    La versione progettata attorno agli MG90S è congelata nel branch mg90s
    (commit 5001f71). Su main i suoi documenti e script passano in docs/mg90s/
    e cad/script/mg90s/ come sola consultazione. CLAUDE.md riscritto per la
    versione con gli MG996R di AZDelivery: stato, decisioni dell'utente, dati
    già letti su fonte primaria, cosa resta valido, prossimi passi. Nuovo
    registro delle decisioni da D-041.
2026-10-08 Studio per la versione MG996R; main ripulito
    - docs/studio-componenti.md: servo MG996R di AZDelivery (datasheet letto:
    11 kgf*cm e 2,5 A di stallo a 6 V), alimentazione (rail a 6,0 V, tre
    regolatori, potenza fuori dalla SSC-32, fusibile, cavi), giunti, stampa,
    misure da chiedere.
    - docs/dimensionamento.md: bilancio di massa preliminare (2,6 kg), assetti
    e coppie; marcia classica attorno al 50 % dello stallo dichiarato.
    - docs/dimensioni-componenti.md: MG996R, batteria da 5200 mAh, e i dati
    ancora validi di ESP32, SSC-32 e camera.
    - calc/: script riparametrizzati sugli MG996R.
    - cad/script/lib_assieme.py: funzioni generiche per istanze, giunti,
    interferenze e pose, estratte dagli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
    [rif_componenti.py, zampa.py]
2026-10-08 BOM v2.0 della versione MG996R, approvato
    - docs/BOM.md: due regolatori Pololu D42V110F6 (uno per lato della SSC-32),
    potenza portata alle file degli header dal retro della scheda, fusibile da
    30 A, batteria OVONIC 2S 5200 mAh gia' in possesso, cuscinetti 5x10x4 con
    perno da 5 mm, squadrette in alluminio a 25 denti.
    - docs/studio-componenti.md: aggiornato con le risposte dell'utente
    (servo non misurabili, buck della v1 non riusato, batteria da dimensionare).
    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
2026-10-08 Fase 4: architettura della zampa (D-047)
    - Tre architetture indipendenti giudicate da tre revisori
    (docs/ricerca/zampa-architetture.json): base 'scalata' con correzioni.
    - Lunghezze coxa 55, femore 65, tibia 110: andature tutte libere,
    ginocchio al 34 % dello stallo, femore al 49 %.
    - calc/zampa_escursioni.py: verifica 2D parametrica delle escursioni.
    - docs/progetto-meccanico.md: architettura e quote della zampa.
    - BOM D2: perni 5 x 12.
2026-10-08 Fase 4: zampa v0 modellata in Fusion con giunti veri
    - cad/script/zampa.py: parametri, coxa, ponte, femore A e B, tibia,
    istanze di servo/squadrette/cuscinetti/perni, giunti, limiti,
    misura della posa, scansione delle interferenze.
    - D-048: giunto della coxa con il ponte libero in senso assiale,
    il peso passa tutto dal cuscinetto.
    - rif_componenti.py: perno 12 mm, rigenerazione di un solo ingombro.
    - Verifica 3D: femore da -45 a +85, ginocchio fino a 30 (con il femore
    alto); tutte le 212 pose di marcia libere.
    [rif_componenti.py, zampa.py]
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2026-10-09 Corpo v0 e assieme con sei zampe (D-050)
    - cad/script/corpo.py: base con tunnel, baie, sei gondole, bugne della
    SSC-32; chiglia; coperchio provvisorio.
    - cad/script/assieme.py: servo e cuscinetti di coxa ed elettronica nel
    corpo, sei istanze di Zampa, giunti di coxa alla radice, controlli.
    - Verifiche: nessuna interferenza nella posa di riferimento; coxe libere
    a +-35 una alla volta; zampe vicine a contatto a 34 gradi.
    - docs/ricerca/corpo-disposizioni.json, immagine dell'assieme.
2026-10-09 Corpo v0.1: chiglia avvitata, regolatori sulla parete della baia, vassoio dell'ESP32 con torretta della camera
    Verificati: nessuna interferenza nella posa di riferimento, zampe vicine
    libere a 31 gradi, ciclo a tripode libero a 100/45 e 70/70.
2026-10-09 Corpo v0.2: sportello della batteria, vano di coda (F1, T-plug), Wago, gonne del coperchio
    Nessuna interferenza; coxe libere a +-35 e tra vicine a 31; ciclo a tripode
    100/45 libero.
2026-10-09 Corpo v0.3: correzioni dalla revisione (D-051)
    - Batteria sfilabile dal retro (viti posteriori della chiglia sotto le baie).
    - Pareti di collegamento tra gondole, baie e tunnel.
    - Regolatori su slitte stampate tra guide (fori veri del Pololu dallo STEP).
    - Camera girata: il flat esce in alto e arriva all'ESP32.
    - Vassoio su distanziali M3, Wago nelle baie posteriori, T-plug sopra F1,
    fessure dei cavi accanto a F1, sportellino di servizio nel coperchio.
    - Verifiche: nessuna interferenza, coxe libere, ciclo libero a 70/70,
    batteria sfilata di 160 mm senza urti.
    - docs/ricerca/corpo-v0-revisione.json; BOM B18 e D10 aggiornati.
    [zampa.py]
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2026-10-09 STL delle parti della zampa v0.1 e istruzioni per il provino della culla
    [Coxa.stl, Coxa_Ponte.stl, Femore_A.stl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]
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2026-10-09 Fascette dei cavi lungo la zampa: feritoie e gola nel ponte, fascetta attorno al femore (D-058)
    [Coxa_Ponte.stl]
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2026-10-09 D-063: carapace verificato, masse (2910 g, femore 51 %), STL di tutte le parti, render a colori, documenti
    [Corpo_Base.stl, Corpo_Carapace.stl, Corpo_Chiglia.stl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]
2026-10-09 D-064: piedino in TPU sulla punta dello stinco; STL, render e documenti
    [Cover_Tibia.stl, Piedino.stl, Tibia.stl]
2026-10-09 D-065: tibia simmetrica sul piano della zampa, lama B con viti M2 in inserti, materiali scelti dall'utente; STL, render e documenti
    [Cover_Femore_B.stl, Cover_Tibia.stl, Femore_B.stl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]
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2026-10-09 esporta_robot.py: geometria, masse e inerzie per parte, limiti, cicli verificati, mesh dei segmenti e pose di controllo dal modello (robot/cad.json, robot/pose_cad.json, robot/mesh); robot.yaml con c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
    [corpo.stl, coxa.stl, femore.stl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]
2026-10-09 tools/descrizione.py: robot.yaml + cad.json e cinematica di riferimento (diretta uguale al CAD entro 0,0001 mm); impronta di cad.json in robot.yaml
    [robot.yaml]
2026-10-09 2.1.0 blocco A (D-066): punta dello stinco e piedino per l'FSR, tasca e gola dei fili, sede della striscia LED e diffusore della tibia, punti con nome; scansione ripetibile in zampa.py; esportazione 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
    [femore.stl, robot.yaml, tibia.stl]
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2026-10-09 Progetto ESP-IDF v6.1 per esp32s3: app_main con rail spento e autotest del nucleo, ctrl a 50 Hz da timer hardware sul core 1 in modo OMBRA, altri compiti di software.md 2.2 come scheletri, partizioni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
    [partitions.csv]
2026-10-09 Header e vettori rigenerati sul cad.json del blocco A; .gitignore per ambiente Python e build; versi uguali per tutte le zampe in software.md
    [robot.yaml]
2026-10-09 S0: tools/genera_modelli.py genera URDF e MJCF dalla descrizione (cinematica uguale al CAD, masse, primitive di collisione, servo); sim/ con emulatore della SSC-32, tripode in Python uguale ai cicli 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
    [esapode.urdf]
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2026-10-09 URDF e MJCF rigenerati sul cad.json del blocco A (massa 2950,7 g); 57 test Python e app verificati dopo l'unione
    [esapode.urdf]
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2026-10-09 2.1.0 blocco B (D-066): 2813 fra SSC-32 e portafusibile, IMU e ADC sotto il vassoio, prese dei piedi, spie dei rail, ToF frontale con finestra e tappo, ToF posteriore, supporti degli INA260, anello d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
    [corpo.stl, coxa.stl, esapode.urdf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]
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2026-10-09 2.1.0 blocco C (D-066): dime di posa 1 e 2 per tutte le zampe, verificate con i controlli a ±2°, e cavalletto da banco verificato con le zampe in 18 pose basse; STL di tutte le parti aggiornati, attr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
    [Attrezzo_Cavalletto.stl, Corpo_Base.stl, Corpo_Carapace.stl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]
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2026-10-10 Versione 2.1.1 (D-067): camera dell'anello Ø32 × 6 con il fondo e due sedi da un pixel, fermo dei fili sulla culla della tibia, striscia a 60 LED/m e un pixel per lobo, schema del cablaggio in docs/c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
    [Corpo_Fascia.stl, Corpo_Fondo_Anello.stl, Tibia.stl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]
2026-10-10 2.1.1: modelli URDF e MJCF rigenerati dalla descrizione (la CI sim li trovava vecchi); in CLAUDE.md la procedura elenca tutti i generatori
    [esapode.urdf]
2026-10-10 BOM v2.1 (D-068): prezzi e link d'acquisto letti il 10 ottobre 2026, carrelli per negozio con le spedizioni e costo totale (circa 486 € per le voci approvate, predisposizioni X a parte); striscia LED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
    [esapode.urdf, robot.yaml]
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2026-10-10 Versione 2.1.2 (D-069): predisposizioni scelte (approvate e backlog), prese delle luci delle tibie, provino di luce, presa del T-plug verificata, tocco dai sensori esistenti in software.md; BOM con l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
    [Attrezzo_Provino_Luce_Bianco.stl, Attrezzo_Provino_Luce_Nero.stl, Corpo_Base.stl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]
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2026-10-11 Versione 2.1.3 (D-070): lame del femore come il guscio della tibia, chiuse su teste e mozzi, con la feritoia a intarsio nero; nessuna copertura superiore
    - zampa.py: lame nuove (sagoma da X 40 a 135,5 con tre angoli smussati, faccia piana con smusso 3 x 2, tasche cieche per le 12 teste M3 sulla A e per i perni sulla B), intarsi Cover_Femore_A/B_Feritoia stampati con la lama; tolti i parametri delle lame bombate
    - verifiche in CAD: zampa libera (81 pose, 17 controlli su 20), coxe a +-35, vicine libere a 30,5 e a contatto a 31 (gioco a 30 di 3,58 mm), carapace a 3,96 mm, cicli e rotazione liberi
    - massa attesa 3060,6 g (femore al 53 % dello stallo): calc, robot.yaml, regressioni e test del con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
2026-10-11 Piano della versione 2.1.4: lame del femore con la sagoma del femore (come le lame di D-061) e l'estetica della 2.1.3
2026-10-11 Versione 2.1.4 (D-071): lame del femore con la sagoma del femore e l'estetica della 2.1.3, feritoia al centro
    - zampa.py: sagoma come le lame di D-061 (fascia a Z +-14,5, teste esagonali, rialzo da X 80 a 97 con rampe a 30 e 45 gradi), spigoli vivi con lo smusso 3 x 2; feritoia e viti della lama B a Z 1,5, vite lato ginocchio a X 89 (inserto di Femore_B spostato con la quota dello schizzo)
    - verifiche in CAD: zampa libera, coxe a +-35, vicine libere a 30,5 e a contatto a 31, carapace a 4,58 mm, cicli e rotazione liberi
    - massa attesa 3043,5 g (femore al 53 % dello stallo); STL, robot, generati, mesh e render aggiornati
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2026-10-11 Piano della versione 2.1.6: doppia predisposizione per IMU (MPU-6500 e Pololu) e microfoni (MS3625 e Adafruit), amplificatore generico con le bugne corrette, altoparlante tondo da 15 mm
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2026-10-11 Versione 2.1.6 (D-074): doppia predisposizione di IMU (GY-6500 su Corpo_Piastrina_IMU sopra le bugne della Pololu) e microfoni (MS3625 centrate da Corpo_Lunette_Microfoni nella sede della Adafruit), 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
2026-10-11 Piano della guida di montaggio illustrata (D-075): Blender per le immagini, PDF con Chrome allegato al tag, A4 orizzontale, zampa descritta una volta, schemi delle schede da progettare, problemi vers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
2026-10-11 Guida, F2: passi della tibia (6.01-6.10) e primi problemi della zampa scritti dall'estrattore; viste della tibia e morsa nel catalogo; viti strette in un passo dopo quello in cui si mettono (stringi)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
2026-10-11 Guida, F2: correzioni dei due verificatori sulla tibia (guscio e diffusore rinviati dopo le alette strette, cuscinetto prima del servo con pollice o tubetto, gommini, servo infilato dal lato A, FSR e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
2026-10-11 Guida, F3 pronta: uscite separate per sezione (build/guida/sezioni/<id>/), controlli sui passi limitati alle sezioni scelte, file degli altri a meta' tollerati; passi solo testo, figure da file, tabe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
2026-10-11 Guida, F3c parte A: passata di qualita' sulle sezioni 0-3, 6, 7, 9-12, 14, 15 (zone in giallo, pose della zampa, etichette, provini, dime e cavalletto dal CAD), 16 problemi nuovi
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2026-10-12 Guida, F3b: schemi su millefori della basetta dell'ESP32 e della scheda del carapace (lato componenti e lato saldature specchiato), schemi.md con reti, fili, ordine di saldatura e prove al multimetro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
2026-10-15 Guida: PDF completo da 98 a 25,4 MB (immagini appiattite con gli ottetti a 64 colori, errore medio 1/255; PDF di Chrome riscritto con pikepdf e immagini indicizzate esatte)
2026-10-15 Guida, F5: registro unico dei problemi (138 voci da 207: 6 bloccanti, 55 importanti, 77 minori; 37 domande per l'utente, 9 gruppi di decisioni in blocco, caso di controllo 4 su 8 piu' 1 in parte); ve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
2026-10-15 Arresto 2: P-006, schema della striscia dei partitori (8 canali dell'ADS7830: FSR dei piedi e NTC) con generatore; problemi S-28..S-31 (posto nel corpo, viti vicino alle piazzole, condensatori, piedi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
2026-10-18 PCB, F1: genera_contorni.py (sagome, fori e zone senza rame dal CAD, --controlla senza KiCad), aree senza rame in scheda_kicad; tests/test_pcb.py con i casi di controllo
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2026-10-18 PCB-C, F4: piazzamento (J2 sul bordo di coda, griglia di piazzole Ø1,5, ToF e R-MIC nell'ala +Y, CE1 in piedi nell'ala -Y con 14 mm liberi sotto); piazzole per fili proprie, zone senza rame sopra le 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
2026-10-18 2.1.9: prova dello spazio della scheda dei partitori nel CAD (sagoma utile circa 33 x 8,6: a passo 2,54 non entra), strade da scegliere; stato del piano e CLAUDE.md
2026-10-18 D-084: scheda dei partitori a quattro strati con pettine a due file, schema, piazzamento e sbroglio con DRC a zero (sagoma di prova fino alla 2.1.9); kit B8 a reoforo, 100 nF 0805 da approvare (PCB2)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
2026-10-18 2.1.9, blocchi B-D: copia di ripristino della 2.1.8 in Fusion; scheda dei partitori nel CAD (par_l 33,8, par_w 8,6, par_dy, smusso 3,2 per uno spigolo della base, foro di testa a 76,2, pettine a due 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
